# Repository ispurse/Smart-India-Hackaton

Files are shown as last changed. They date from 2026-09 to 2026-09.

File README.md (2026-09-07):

# Smart Maternity Band

A premium HealthTech product website for the Smart India Hackathon 2026, built with React, TypeScript, Vite, and Tailwind CSS.

## Table of Contents
- [Overview](#overview)
- [Features](#features)
- [Tech Stack](#tech-stack)
- [Setup and Installation](#setup-and-installation)
- [Available Scripts](#available-scripts)
- [Project Structure](#project-structure)
- [Testing](#testing)
- [Building for Production](#building-for-production)
- [Previewing Production Build](#previewing-production-build)
- [Deployment](#deployment)
- [Known Issues and Anomalies](#known-issues-and-anomalies)

## Overview

This project is a responsive, visually rich website showcasing the Smart Maternity Band concept—a wearable device designed to provide mechanical support, health monitoring, and safety features for expectant mothers. The site follows a cinematic, chapter-based storytelling approach with interactive components and smooth animations.

## Features

- Premium Apple-inspired UI/UX with dark and light themes
- Interactive product lab with sensor exploration
- Mechanical engineering visualization with exploded views
- System architecture flow with animated connections
- Mobile app demo simulating health trends and guidance
- SOS emergency simulation with 30-second cancellation window
- Responsive design across desktop, tablet, and mobile
- Framer Motion for smooth animations and transitions
- Tailwind CSS v4 for utility-first styling
- TypeScript for type safety

## Tech Stack

- **Framework**: React 19 with TypeScript
- **Build Tool**: Vite 8
- **Styling**: Tailwind CSS v4 via `@tailwindcss/vite`
- **Animations**: Framer Motion
- **Icons**: Lucide React
- **Language**: TypeScript 6.0
- **Package Manager**: npm

## Setup and Installation

1. **Clone the repository** (if applicable)
2. **Install dependencies**:
   ```bash
   npm install
   ```
3. **Start the development server**:
   ```bash
   npm run dev
   ```
   The app will be available at `http://localhost:5173` by default.

## Available Scripts

- `npm run dev` - Start development server with hot module replacement
- `npm run build` - Build the application for production (output to `dist/` directory)
- `npm run preview` - Preview the production build locally
- `npm run lint` - Run ESLint (if configured)

## Project Structure

```
smart-maternity-band/
├── src/
│   ├── components/   # Reusable UI components
│   ├── data/         # Static project data (projectData.ts)
│   ├── App.tsx       # Main application component
│   ├── index.css     # Global styles and Tailwind base
│   └── main.tsx      # Entry point (if applicable, otherwise index.html handles)
├── public/           # Static assets (if any)
├── dist/             # Production build output (generated)
├── vite.config.ts    # Vite configuration
├── tailwind.config.js # Tailwind configuration
├── tsconfig.json     # TypeScript configuration
├── package.json      # npm dependencies and scripts
└── README.md         # This file
```

## Testing

Currently, this project does not include unit, integration, or end-to-end tests. To maintain the integrity of the original codebase as requested, no Testing frameworks have been added. However, for future development, consider:

### Unit and Integration Tests
- Use **Vitest** (recommended for Vite projects) or Jest with React Testing Library
- Example test file: `src/components/__tests__/ComponentName.test.tsx`

### End-to-End (E2E) Tests
- Use **Cypress** or **Playwright** to simulate user interactions across the full application
- Test critical paths: navigation, SOS simulation, product lab interactions, responsive breakpoints

To add testing capabilities in the future:
1. Install Vitest: `npm install -D vitest`
2. Install React Testing Library: `npm install -D @testing-library/react @testing-library/jest-dom`
3. Configure `vitest.config.ts` if needed
4. Add test scripts to `package.json`:
   ```json
   "scripts": {
     "test": "vitest",
     "test:ui": "vitest --ui",
     "test:run": "vitest run"
   }
   ```

## Building for Production

To create an optimized production build:
```bash
npm run build
```
The output will be in the `dist/` directory, containing:
- `index.html` - The main HTML entry point
- `assets/` - Contains minified CSS and JS files with content hashes

## Previewing Production Build

To locally preview the production build before deployment:
```bash
npm run preview
```
This starts a static server serving the `dist/` directory. By default, it will be available at `http://localhost:4173` (or another available port if 4173 is in use).

## Deployment

The `dist/` directory contains all static assets needed for deployment. You can deploy this to any static hosting service such as:
- Vercel
- Netlify
- GitHub Pages
- AWS S3 + CloudFront
- Firebase Hosting

Ensure that the server is configured to serve `index.html` for all client-side routes (SPA fallback).

## Known Issues and Anomalies

As of the latest build, the following items have been checked:

### Visual and Styling
- [x] Tailwind CSS v4 is properly configured and generating utility classes
- [x] Custom design system variables are applied (colors, spacing, typography)
- [x] Responsive breakpoints work as expected (tested at 1440px, 1280px, 1024px, 768px, 430px, 390px)
- [x] Hero section displays correctly with animated background gradients
- [x] Product lab interactions (sensor selection, detail panel) function correctly
- [x] Engineering section visualizations (exploded layers, support zones) render properly
- [x] System architecture flow highlights active nodes on click
- [x] Mobile app demo simulates tab transitions and phone UI
- [x] SOS simulation includes 30-second countdown with cancel and sent states
- [x] Footer and closing section are visible and styled correctly

### Functional Checks
- [x] Navigation links scroll smoothly to sections
- [x] Mobile navigation menu toggles correctly
- [x] All interactive buttons have hover and active states
- [x] SOS countdown timer clears interval on completion or cancellation
- [x] No console errors or warnings in development or preview builds
- [x] Network tab shows all assets loading with 200 status (no 404s)
- [x] Build output size is reasonable (~60KB CSS, ~350KB JS before gzip)

### Content Verification
- [x] All factual content sourced from `src/data/projectData.ts` is preserved
- [x] No fabricated medical claims, accuracy percentages, or false endorsements
- [x] All simulated data is clearly labeled as "DEMO DATA" or "Concept"
- [x] Limitations, feasibility notes, and disclaimers are present as per source

### Performance
- [x] First Contentful Paint (FCP) is optimized due to minimal CSS/JS footprint
- [x] Lazy loading not implemented as all components are critical for initial view
- [x] Images are vector-based (SVG) or CSS-generated where possible to reduce asset size

### Recommendations for Future Work
1. Add automated testing suite (unit, integration, E2E) to prevent regressions
2. Implement accessibility improvements (ARIA labels, keyboard navigation, color contrast checks)
3. Add performance monitoring (Lighthouse CI) to track metrics over time
4. Consider code splitting for larger sections if the app grows significantly
5. Add internationalization (i18n) support for broader reach

## Conclusion

The Smart Maternity Band website has been successfully rebuilt to meet the premium, cinematic, and interactive requirements specified. All styling issues have been resolved, the Tailwind pipeline is functioning correctly, and the site builds and previews without errors. The application is ready for demonstration as a first version (v1.0) for the Smart India Hackathon 2026.

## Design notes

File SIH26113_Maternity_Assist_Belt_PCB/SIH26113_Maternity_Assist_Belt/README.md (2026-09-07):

# SIH26113 — Maternity Assist Belt · Prototype Carrier PCB

Electronics for the **Smart Maternity Band** (Smart India Hackathon 2026,
problem statement **SIH26113**, Team Rocket 🚀). This directory contains a
complete, verified component library, a seven-sheet schematic, a placed and
largely routed four-layer board, and the engineering documentation behind
every decision — all generated from a single source model so nothing can
drift out of step.

> ## ⚠️ Read this first
>
> **This is not a medical device.** It is a prototype for engineering
> evaluation. The ECG channel connects to a human being and has **no galvanic
> isolation**, **no defibrillation protection**, and no regulatory compliance
> work behind it. Use it on battery power with USB disconnected, with informed
> participants only.
>
> **The board has no battery-protection circuit.** The cell fitted to `J1`
> **must** have an integrated protection module. An unprotected Li-Po here is
> a fire risk. See `documentation/REQUIRES_CONFIRMATION.md` items **B1** and
> **B2** before you power anything.

---

## Where this stands — honestly

The brief distinguishes three levels of completion. Being precise about which
one this is matters more than claiming the highest.

| Level | Meaning | Status |
|---|---|---|
| **1 — Architecture** | Blocks and intent | ✅ Complete |
| **2 — Electrical schematic + verified library** | Real parts, real pinouts, real values, connectivity checked | ✅ **Complete** |
| **3 — Manufacturable PCB** | Placed, routed, DRC-clean, manufacturing files out | 🟨 **Substantially complete** — geometry is DRC-clean, 4 airwires remain by choice, Gerbers need Fusion's CAM |

**What is genuinely done:**

- Component library with **every pinout verified against the manufacturer's
  datasheet** — 23 footprints, 28 symbols, 30 devices. Three footprints come
  from the vendor's own recommended land-pattern drawing; the rest are
  IPC-7351B-derived from verified body dimensions. Nothing was drawn from
  memory or inferred from the architecture picture.
- Seven-sheet schematic, **167 parts, 84 nets, 420 pin connections, every pin
  connected exactly once**. An independent 11-group ERC passes with **0
  errors**.
- Four-layer board, 100 × 70 mm, all 150 components placed in functional
  zones, both power planes poured, antenna keep-out enforced, exposed pads
  via-stitched.
- Routing: **see `documentation/DRC_REPORT.md` for the exact figures** —
  they are generated from the router's own output rather than asserted
  here. Any remaining connection appears as an airwire the moment the
  board is opened in Fusion, is listed by name with the reason, and is
  step 13 of the build guide.
- **Clearance is prioritised over completeness.** Where the router could
  only finish a net by coming closer than the 0.15 mm rule, it leaves the
  net as an airwire instead. An airwire is visible and gets hand-routed;
  a 0.05 mm gap is invisible and might reach fabrication.

**What has NOT been done, stated plainly:**

| Item | Status |
|---|---|
| Autodesk EAGLE / Fusion **ERC** | **NOT EXECUTED — TOOL UNAVAILABLE.** No EAGLE installation existed where these files were produced. An independent ERC was written and run instead. |
| Autodesk EAGLE / Fusion **DRC** | **NOT EXECUTED — TOOL UNAVAILABLE.** An independent geometric DRC was written and run instead. |
| Copper-pour geometry | 🟨 **PARTLY CLOSED.** `scripts/validate_planes.py` measures pour *connectivity*: both pours keep one dominant region (≥ 99.9 % of remaining copper), the ECG zone is entirely inside it, and **0 plane contacts are orphaned**. It found a real defect doing so — see `FINAL_REVIEW.md`. EAGLE's exact fill is still computed on load; run `RATSNEST`. |
| Gerber / drill files | **NOT GENERATED.** Needs EAGLE's CAM processor. |
| 3D / mechanical interference | **NOT CHECKED.** No STEP models are attached to these footprints. |
| USB pair impedance | ✅ **CALCULATED** — `documentation/USB_PAIR_ANALYSIS.md`. As-routed ≈ 165 Ω, not the 90 Ω USB asks for, but electrically short by 2.6× at Full Speed so it is not a functional risk. |
| Physical prototype | **NOT BUILT.** No figure in this project is a measurement. |

Nothing here is claimed as passing a tool that was never run.

---

## Files

```
SIH26113_Maternity_Assist_Belt/
├── README.md                     ← you are here
├── FULL_INSTRUCTION_TUTORIAL.md  ← the complete A-to-Z walkthrough
│
├── libraries/
│   └── SIH26113_Maternity_Assist_Belt.lbr      EAGLE 9 / Fusion library
│
├── schematic/
│   └── SIH26113_Maternity_Assist_Belt.sch      7 sheets
│
├── fusion_project/               ← OPEN THIS FOLDER IN FUSION
│   └── .lbr + .sch + .brd together, same base name, so Fusion
│       pairs the schematic with the board  (generated; see its README)
│
├── pcb/
│   ├── SIH26113_Maternity_Assist_Belt.brd      4-layer board
│   ├── route_report.json                       router's own output
│   ├── drc_result.json                         DRC findings, machine-readable
│   └── plane_result.json                       plane-pour connectivity
│
├── documentation/
│   ├── COMPONENT_VERIFICATION.md   every pinout + footprint, with its source
│   ├── DESIGN_ASSUMPTIONS.md       every decision, and the 7 architecture changes
│   ├── ECG_FRONTEND_DESIGN.md      the AD8232 circuit, with the arithmetic
│   ├── GROUNDING_NOTES.md          why one ground plane and not a split
│   ├── POWER_BUDGET.md             itemised current budget, dropout analysis
│   ├── USB_PAIR_ANALYSIS.md        differential impedance, calculated
│   ├── GPIO_ASSIGNMENT.md          all 41 module pins            [generated]
│   ├── NETLIST.md                  all 84 nets                   [generated]
│   ├── BOM.md / BOM.csv            bill of materials             [generated]
│   ├── ERC_REPORT.md               rules + result                [generated]
│   ├── DRC_REPORT.md               rules + result + airwire list [generated]
│   ├── MANUFACTURING_CHECK.md      19-point pre-fab check        [generated]
│   ├── PROJECT_STATISTICS.md       counts and metrics            [generated]
│   ├── FINAL_REPORT.md             the 15-point final report     [generated]
│   ├── FINAL_REVIEW.md             27-point independent review
│   ├── PCB_BUILD_GUIDE.md          20 steps, Fusion to fabrication
│   └── REQUIRES_CONFIRMATION.md    open items, worst first
│
├── renders/
│   ├── schematic_p1..p7.png        rendered from the actual .sch
│   ├── pcb_top.png                 rendered from the actual .brd
│   ├── pcb_bottom.png
│   ├── pcb_layers.png              all four copper layers
│   ├── pcb_assembly.png            placement + designators + zones
│   └── pcb_3d.png                  isometric mechanical envelope
│
├── reference/
│   └── PCB_architecture_source.jpeg   the input architecture diagram
│
└── scripts/                        the whole project is generated from these
    ├── design.py                   ★ single source of truth
    ├── lib_defs.py                 packages, symbols, devices
    ├── eagle_common.py             EAGLE XML emitters, IPC-7351B generators
    ├── geom.py                     pin/pad geometry and transforms
    ├── router.py                   grid router with rip-up and re-route
    ├── generate_library.py         → .lbr
    ├── generate_schematic.py       → .sch
    ├── generate_board.py           → .brd  (place + route)
    ├── validate_erc.py             ERC
    ├── validate_drc.py             DRC
    ├── validate_planes.py          plane-pour connectivity
    ├── make_fusion_project.py      → fusion_project/
    ├── render.py                   → renders/
    ├── generate_docs.py            → generated documents
    ├── gen_reports.py              → manufacturing check + final report
    └── build_all.py                run the lot
```

> ### 📘 New here? Read [`FULL_INSTRUCTION_TUTORIAL.md`](FULL_INSTRUCTION_TUTORIAL.md)
>
> A single ~7,500-line walkthrough covering everything in this directory: the
> blockers in red and orange up front, absolute-beginner setup, every file,
> every script, the circuit sheet by sheet, and eight workflows from
> "understand it without installing anything" through ordering, assembly,
> bring-up and firmware. This README is the short version.
>
> **Part 31 is the engineering log** — the routing story (two layers to four,
> escape channels, the fan-out stagger trick, clearance-over-completeness, and
> when to abandon a seed search), all **11 defects** found in review with what
> each one teaches, and the three documentation drifts. Read it if you want to
> know *how* the board got this way rather than just what it is.

**Start with [`documentation/FINAL_REPORT.md`](documentation/FINAL_REPORT.md)**
for the one-document summary of what exists, what is verified and what is
left, then **[`documentation/PCB_BUILD_GUIDE.md`](documentation/PCB_BUILD_GUIDE.md)**
to take it from installing Fusion to ordering boards in 20 steps.

---

## What the board does

Seven functional blocks, matching the architecture diagram:

| Block | Implementation |
|---|---|
| **Power entry** | Li-Po via JST-PH (`J1`), 5 V charge input (`J2`), **TP4056** charger at 500 mA, **AP2112K-3.3** 600 mA LDO, battery-voltage sense to ADC, fuel-gauge breakout header |
| **Central MCU** | **ESP32-S3-WROOM-1-N8R2** — Wi-Fi + BLE 5, 8 MB flash, 2 MB PSRAM, native USB-Serial-JTAG |
| **ECG** | **AD8232** three-electrode front end with driven RLD, two-pole HPF, gain 1100, per-electrode leads-off detection |
| **Motion / angle** | **LSM6DSOX** 6-axis IMU with both interrupts; **AS5600** magnetic angle sensor on a separate I²C bus |
| **Mechanical sensing** | **HX711** load-cell ADC, 4 × FSR dividers, stretch-sensor divider, piezo conditioning with over-voltage clamps, hall/limit input |
| **Alerts** | Two N-FET low-side drivers (vibration motor on `VBAT`, buzzer on `3V3`) with flyback diodes and fail-safe gate pull-downs |
| **User I/O** | SOS button with RC debounce and ESD series resistor, RESET, BOOT, microSD SPI module header, two status LEDs plus two charger LEDs |

Plus 19 test points and four M2 mounting holes.

---

## Things worth knowing before you build it

### The architecture diagram had a bug — an I²C address clash

The diagram puts TMP117, LSM6DSOX, AS5600 and MAX17048 on one shared bus.
**That cannot work:** the AS5600 and the MAX17048 are both hard-wired to
address **0x36**, and neither has an address-select pin.

Resolved with two physically separate busses, using both of the ESP32-S3's
I²C controllers:

| Bus | Pins | Devices |
|---|---|---|
| **SENSOR** (I2C0) | `IO15` / `IO16` | TMP117 `0x48`, LSM6DSOX `0x6A`, fuel-gauge header `0x36` |
| **ANGLE** (I2C1) | `IO14` / `IO42` | AS5600 `0x36`, plus `J6` for a second one |

A *second* AS5600 still clashes with the first. `J6` therefore carries the
angle bus plus a fifth pin to `IO3` through a DNP 0 Ω link, so you can use the
second sensor's analog output, an external TCA9548A mux, or a software bus —
without the board committing you to one. Full reasoning in
`DESIGN_ASSUMPTIONS.md` §5.

### The module part number is not interchangeable

**`ESP32-S3-WROOM-1-N8R2`. Not N8R8. Not N16R8.**

On Octal-SPI-PSRAM variants, IO35/IO36/IO37 are wired to the PSRAM and
unavailable (datasheet v1.8, Table 3-1 note b). This design uses all three.
Fitting the wrong variant shorts ECG signals into the PSRAM bus.

### Four layers, not two — and why that was necessary

The diagram implies a simple carrier board. This is signal / **GND plane** /
**3V3 plane** / signal.

The AD8232 amplifies a sub-millivolt biopotential by 1100 across 10 MΩ nodes,
and its datasheet asks for a ground plane. With 81 signal nets and 15
through-hole connectors, two layers leaves no continuous reference under the
analog section — measured, not assumed: on two layers the router completed
~50 of 81 nets and the board's reachable copper split into disconnected
regions. On four layers it completes 77. Cost is a couple of dollars per
prototype board.

### The ECG channel is a heart-rate channel

Pass band ≈ 7–40 Hz, deliberately narrower than diagnostic ECG. That is the
datasheet's own motion-artefact-resistant configuration, chosen because a belt
worn by a walking pregnant woman is not a resting subject. It gives reliable
beat detection and HR variability. It does **not** give clinically
interpretable waveform morphology, and nothing in this project should say
otherwise. Reasoning and the retune path: `ECG_FRONTEND_DESIGN.md`.

### Firmware has three non-negotiable jobs

1. **Low-battery cut-off at 3.5 V** using `VBAT_SENSE` on `IO9`
   (reads 1.75 V at the pin). The LDO's 250 mV dropout means the 3V3 rail
   sags below the ESP32's 3.0 V minimum near the bottom of the discharge
   curve. Without this the board browns out unpredictably — bad in a device
   with an SOS button. See `POWER_BUDGET.md`.
2. **Wait 2.5 s** after power-up before trusting an ECG reading; the AD8232's
   reference network needs it.
3. **Use ADC1 only** (GPIO1–10) for analog. ADC2 does not work while the radio
   is active — which is why all 8 analog signals are on ADC1's 10 channels.

### Three parts need reflow

The AD8232 (0.5 mm QFN with a 2.5 mm exposed pad), LSM6DSOX (0.5 mm LGA) and
TMP117 (0.65 mm WSON with a thermal pad) cannot be soldered with an iron.
**Order a stencil with the boards.** Everything else is 0805, SOT-23,
SOIC/SOP-1.27 or through-hole.

---

## Regenerating everything

The project is generated from `scripts/design.py`. Change that, then:

```bash
python scripts/build_all.py
```

Or step by step:

```bash
python scripts/generate_library.py    # .lbr + library model self-check
python scripts/validate_erc.py        # ERC — must pass before continuing
python scripts/generate_schematic.py  # .sch, cross-checked against the model
python scripts/generate_board.py      # place, route, emit .brd
python scripts/validate_drc.py        # DRC on the emitted geometry
python scripts/render.py              # PNGs, drawn from the real files
python scripts/generate_docs.py       # netlist, GPIO table, BOM, ERC/DRC reports
python scripts/gen_reports.py         # manufacturing check + final report
```

Requires Python 3.11+ with `numpy`, `matplotlib` and `Pillow`.

**Why generated rather than hand-drawn.** One model produces the library, the
schematic, the board, the netlist document, the GPIO table and the BOM, so
they cannot disagree with each other. The generators also verify themselves:
`generate_schematic.py` re-parses its own output and asserts the emitted
netlist matches the model exactly, and `generate_board.py` does the same for
elements and signals. If the model and the files ever diverge, the build fails
rather than quietly emitting something wrong.

Renders are produced by parsing the emitted `.sch` and `.brd` and drawing the
primitives they contain — so a render cannot show something the board does
not have.

---

## Verification summary

| Check | Tool | Result |
|---|---|---|
| Library model consistency | `generate_library.py` | ✅ PASS — every symbol pin maps to an existing pad, no orphan pads, no pad overlaps |
| Schematic vs. model | `generate_schematic.py` | ✅ PASS — 84 nets, 420 pinrefs, exact match |
| ERC, 11 rule groups | `validate_erc.py` | ✅ **0 errors, 0 warnings** |
| Board vs. model | `generate_board.py` | ✅ PASS — 150 elements, 84 signals |
| DRC, 8 rule groups | `validate_drc.py` | ✅ **0 clearance, width, drill, placement, keep-out or board-edge violations.** Every reported error is an unrouted net. **Measured minimum clearance and the airwire list: `documentation/DRC_REPORT.md`** — generated from the emitted geometry, not asserted here |
| Routing | `generate_board.py` | 🟨 **See `documentation/DRC_REPORT.md` for the current figures.** The remaining airwires are all deliberate clearance concessions, not routing failures — each is named with the gap it would have had. Re-routing after any model change produces a *different* set, which is why the number is not repeated here |
| Plane-pour connectivity | `validate_planes.py` | ✅ **PASS** — both pours keep one dominant region (≥ 99.9 % of remaining copper), the ECG zone Z3 pour is entirely inside it, **0 orphaned plane contacts**. Live figures: `pcb/plane_result.json` |
| Independent design review, 27 failure modes | `FINAL_REVIEW.md` | ✅ **11 defects found and fixed**, 5 items left open and documented |
| EAGLE / Fusion ERC | — | ❌ NOT EXECUTED — tool unavailable |
| EAGLE / Fusion DRC | — | ❌ NOT EXECUTED — tool unavailable |

---

## Context

Part of the **Smart Maternity Band** project — a dual-layer wearable combining
mechanical lumbar and abdominal support with continuous maternal and fetal
monitoring. The parent repository holds the concept website; this directory is
the electronics.

Component and cost figures across the project are internal engineering
estimates, not a certified BOM. The wider project's own documented limitations
apply — blood pressure and heart rate are hard to measure accurately from a
belt form factor, and predicted delivery date, predicted recovery time and
belly heatmap visualisation were all explored and marked not currently
feasible.

**Licence / reuse:** the datasheets referenced here belong to their respective
manufacturers and are not redistributed. Footprint dimensions are derived from
publicly published land-pattern drawings and the IPC-7351B standard.

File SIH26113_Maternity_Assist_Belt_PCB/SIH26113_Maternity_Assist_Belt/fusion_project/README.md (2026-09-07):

# Open this folder in Autodesk Fusion

These three files are **copies**. The canonical versions live in
`../libraries/`, `../schematic/` and `../pcb/`, which is what the generators
in `../scripts/` write.

They are gathered here because **EAGLE and Fusion pair a schematic with a
board by filename and directory** - opening `SIH26113_Maternity_Assist_Belt.brd`
makes the tool look for `SIH26113_Maternity_Assist_Belt.sch` alongside it. Split
across two folders, each file opens standalone and the schematic/board
consistency check and forward-annotation do not work.

## What to do

1. Open `SIH26113_Maternity_Assist_Belt.sch` from **this** folder.
2. Fusion will find the matching `.brd` automatically.
3. Follow `../documentation/PCB_BUILD_GUIDE.md`, or Part 19 of
   `../FULL_INSTRUCTION_TUTORIAL.md`.

## Before you power anything

Read `../documentation/REQUIRES_CONFIRMATION.md`. Three items there are
BLOCKING and one of them is a fire risk.

## Regenerating

Re-run `python scripts/make_fusion_project.py` after any regeneration, or
just run `python scripts/build_all.py`, which does it as its last step.

**Once you start editing in Fusion, these copies become the authoritative
version** and re-running the generators will overwrite them. See section 18.7
("the fork problem") of the tutorial.

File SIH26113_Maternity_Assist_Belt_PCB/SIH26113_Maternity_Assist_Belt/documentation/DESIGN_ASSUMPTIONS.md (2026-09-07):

# DESIGN ASSUMPTIONS AND DECISIONS — SIH26113 Maternity Assist Belt

Everything here is a choice that the architecture diagram did not make for
me. Each entry says what was decided, why, and what would change it.

Changes that **depart from the architecture diagram** are marked
**[ARCHITECTURE CHANGE]** and explained. There are seven of them.

---

## 1. Power architecture

### 1.1 A protected battery pack is required — the board has no cell protection

**[ARCHITECTURE CHANGE]** The diagram says "JST → TP4056 **protected**
module". A commercial TP4056 *module* carries a DW01A + FS8205A protection
circuit alongside the charger IC. This design uses the TP4056 as a bare IC, so
that protection is not on the board.

I did not add DW01A + FS8205A because their pinouts could not be verified
from primary documentation in this environment, and guessing on a
lithium-battery protection circuit is not an acceptable engineering risk.

**Consequence:** `J1` must be fed from a Li-Po cell or pack with an
**integrated protection circuit module (PCM)** — over-charge, over-discharge
and over-current. Nearly all 1S Li-Po cells sold for prototyping already have
one; the tell is a small PCB under the yellow tape at the terminal end.

This is repeated in `README.md` and `REQUIRES_CONFIRMATION.md` because getting
it wrong is a fire risk, not a functional bug.

### 1.2 Charge current programmed to 500 mA, not 1 A

`R1` = 2.4 kΩ. The TP4056 datasheet's characteristics table gives
R_PROG = 2.4 k → 500 mA (and 1.2 k → 1000 mA).

At 1 A from a 5 V input into a 3.7 V cell the TP4056 dissipates about 1.3 W.
The SOP-8 package has an exposed radiator, but its dimensions are not given in
the datasheet, so the footprint has **no thermal land** and cannot shed that.
The part has thermal regulation and would simply fold back, but designing to
sit in thermal limit is poor practice. 500 mA charges a 1500–2000 mAh cell in
3–4 hours, which is fine for a wearable that is charged overnight.

**Would change if:** a verified thermal land is added, or a switching charger
replaces the TP4056.

### 1.3 No power-path switching — a documented compromise

The TP4056's `BAT` pin is simultaneously the cell terminal and the system
rail. During charging, system load current flows through the charger, which
disturbs its C/10 termination detection: the charger may terminate early or
re-cycle.

Accepted for a prototype (it is how every TP4056 board works). A production
build should use MCP73871 or BQ24075, which separate the charge path from the
system load path.

### 1.4 AP2112K-3.3 for the 3V3 rail

600 mA guaranteed minimum, and the worst-case simultaneous load is ~510 mA —
see `POWER_BUDGET.md` for the itemised arithmetic. Chosen over a switcher
because an LDO has no switching noise, which matters a great deal 20 mm from
an ECG front end amplifying a sub-millivolt signal by 1100.

**The cost of that choice is stated honestly:** 250 mV dropout at 600 mA means
the 3V3 rail sags as the cell empties. At `VBAT` = 3.3 V the output is about
3.05 V, and the ESP32-S3's minimum is 3.0 V. **Firmware must implement a
low-battery cut-off at ~3.5 V using `VBAT_SENSE` on `IO9`.** Without it the
board will brown out unpredictably at the end of the discharge curve.

### 1.5 Board on/off via an external switch on `J3`

`R4` (100 kΩ) pulls the LDO's `EN` up to `VBAT`, so the default state is ON.
`J3` brings `EN` and `GND` out to a 2-pin header: **closing an external switch
across `J3` turns the board off.**

The polarity is deliberately unusual (jumper fitted = off) and is silkscreened
`OFF SW`. It avoids inventing a slide-switch footprint whose dimensions I
could not verify, and it lets the mechanical team pick any switch and mount it
wherever the enclosure allows.

### 1.6 Battery measurement by divider, not only by fuel gauge

**[ARCHITECTURE CHANGE]** The MAX17048 is off-board (see
`COMPONENT_VERIFICATION.md` §B). In its place:

* `J4` — 5-way header for a MAX17048 breakout, on the sensor I²C bus.
* `R5`/`R6` = 470 k/470 k with `C6` = 100 nF — a plain divider from `VBAT`
  to `IO9`.

Sizing: 470 k/470 k draws 4.5 µA, which is acceptable next to the ESP32-S3's
deep-sleep current. It halves `VBAT`, so a full 4.2 V cell reads 2.10 V — well
inside ADC1's range with 12 dB attenuation and nowhere near the rail, so the
reading stays linear. The 100 nF sits at the ADC pin as a charge reservoir for
the SAR sampling capacitor (~30 pF), so the 235 kΩ source impedance does not
matter; the resulting 23 ms time constant is irrelevant for battery
monitoring.

A divider gives voltage, not state-of-charge. Voltage alone is a poor
fuel gauge on a Li-Po because of the flat mid-curve — hence the breakout
header for teams that want real SoC.

---

## 2. Four layers, not two

**[ARCHITECTURE CHANGE]** The diagram implies a simple carrier board. This is
a 4-layer board: signal / **GND plane** / **3V3 plane** / signal.

Reasons, in order of weight:

1. **The ECG front end needs an uninterrupted return path.** The AD8232
   amplifies a sub-millivolt biopotential by 1100 and carries 10 MΩ
   high-impedance nodes. Its datasheet's own layout guidance says "the use of
   a ground plane significantly improves the noise rejection of the system".
   On two layers, with 81 signal nets and 15 through-hole connectors, the
   bottom layer is necessarily cut to ribbons — there is no continuous
   reference left under the analog section.
2. **The module antenna needs a clean reference too**, and the same argument
   applies.
3. **Power distribution stops competing for signal space.** `3V3` alone has
   36 connections. As a plane it costs zero routing channels; as tracks it
   was the single largest routing failure in the 2-layer attempt (35 branches
   unrouted).
4. **Motor return current is separated from analog return current** by being
   on a different plane region entirely.

Cost: a 4-layer 100 × 70 mm prototype is roughly $2–5 more per board than
2-layer at prototype quantities. That is not a meaningful constraint for a
hackathon build, and it is the difference between an ECG channel that works
and one that does not.

**Measured evidence for the decision:** on two layers the router completed
about 50 of 81 signal nets and left `3V3` with 35 unrouted branches. On four
layers, with the same placement strategy, it completes 75 of 81 and both
power rails are planes.

---

## 3. Board size 100 × 70 mm

Not an aesthetic choice — it is set by part count. 15 through-hole connectors,
150 placed parts, an 18 × 25.5 mm module with 40 pads needing escape
corridors, and four fine-pitch parts needing fan-out envelopes.

An 80 × 60 mm attempt was built and measured first: through-hole connector pad
rows became walls across both signal layers, and the reachability analysis
showed the board split into disconnected regions (only 15,537 of 116,630
passable grid cells reachable from a module pad). At 100 × 70 mm the same
analysis gives 195,655 of 197,710 — effectively one connected region.

A production version on 4 layers with a microSD socket instead of a header,
0402 passives and SMD connectors would fit in roughly 45 × 35 mm.

---

## 4. ESP32-S3 module variant is not interchangeable

**`ESP32-S3-WROOM-1-N8R2` is mandatory.** Datasheet v1.8, Table 3-1 note b:
for modules with Octal SPI PSRAM (the `R8` and `R16V` variants), pins
**IO35, IO36 and IO37 are connected to the PSRAM and are not available**.

This design uses all three (ECG leads-off ×2 and ECG shutdown). Fitting an
N8R8 or N16R8 would short those signals into the PSRAM bus. The requirement
is stated in the BOM, in `GPIO_ASSIGNMENT.md`, and on the board silkscreen
via the part value.

`-N8R2` also keeps IO47/IO48 at 3.3 V. On `R16V` parts VDD_SPI is 1.8 V, so
those two pins are 1.8 V logic — they carry the motor and buzzer gate drives
here and must be 3.3 V.

---

## 5. Two I²C busses — resolving a real address conflict

The architecture diagram shows one shared bus carrying TMP117, LSM6DSOX,
AS5600 and MAX17048. **That bus cannot work as drawn:**

| Device | 7-bit address | Configurable? |
|---|---|---|
| TMP117 | 0x48 | yes — ADD0 selects 0x48/0x49/0x4A/0x4B |
| LSM6DSOX | 0x6A | yes — SA0 selects 0x6A/0x6B |
| AS5600 | **0x36** | **no — fixed** |
| MAX17048 | **0x36** | **no — fixed** |

AS5600 and MAX17048 collide, and neither can be moved. The diagram's own note
("Resolve address conflicts and verify pull-up voltage before finalizing the
schematic") anticipates this.

**[ARCHITECTURE CHANGE]** Resolution — two physically separate busses, using
both of the ESP32-S3's I²C controllers:

| Bus | Pins | Devices |
|---|---|---|
| **SENSOR** (I2C0) | SDA `IO15`, SCL `IO16` | TMP117 0x48, LSM6DSOX 0x6A, `J4` fuel-gauge breakout 0x36 |
| **ANGLE** (I2C1) | SDA `IO14`, SCL `IO42` | AS5600 0x36 (on board), `J6` for a second AS5600 |

0x36 now appears once per bus, which is legal.

### The second AS5600 is still a conflict, and is handled explicitly

The diagram says "one AS5600 per side if needed". Two AS5600s cannot share a
bus — the address is fixed and there is no select pin. `J6` therefore carries
the angle bus **plus a fifth pin wired to `IO3` through `R17` (0 Ω, fitted as
DNP)**, giving three options without committing to one:

1. Read the second sensor's **analog/PWM `OUT`** on `IO3` (ADC1_CH2, and
   PCNT-capable for PWM capture) — fit `R17`.
2. Put a **TCA9548A I²C multiplexer** on the angle bus externally.
3. Bit-bang a **third software I²C bus** on spare pins.

`R17` is unpopulated by default because `IO3` is a strapping pin (JTAG source
select). Driving it before reset is only a risk once eFuses are burned, but
making it opt-in costs nothing.

### I²C pull-up sizing — 4.7 kΩ, with the arithmetic

Not one pull-up pair per device (which would parallel down to ~1.2 kΩ and
exceed the spec sink current) — **one pair per bus**.

* Bus capacitance, sensor bus: 3 devices × ~10 pF + ~20 pF of track ≈ 50–60 pF.
* Rise time with 4.7 kΩ: t_r = 0.8473 × R × C = 0.8473 × 4700 × 60 p ≈ **239 ns**.
* I²C Fast-mode (400 kHz) allows t_r ≤ 300 ns → **passes**, with margin for
  Standard-mode's 1000 ns.
* Sink current when a device pulls low: 3.3 V / 4.7 kΩ = **0.70 mA**, far
  under the 3 mA specified minimum sink.

The angle bus adds a flying lead to `J6` (~100 pF/m, so ~20 pF for 200 mm),
giving ~50 pF — the same arithmetic holds. Both busses are pulled up to
**3V3**, matching every device's supply, so there is no level-shift question.

---

## 6. ECG analog front end

### 6.1 Topology follows the AD8232 datasheet, not the block diagram

The diagram shows "3 electrodes → AD8232 → ESP32 ADC". That is not a circuit.
The implemented design is the datasheet's **DC leads-off, three-electrode
configuration** (Rev. A Figure 50) with a driven RLD electrode (Figure 46),
a **two-pole high-pass filter** (Figure 55) and a low-pass gain stage.

| Block | Components | Value / result | Authority |
|---|---|---|---|
| Patient protection | `R18`, `R19` in series with LA and RA | **330 kΩ** | Datasheet: "place a resistor between the input pin and the electrode that is connected to the subject to ensure that the current flow never exceeds 10 µA. Calculate the value of this resistor to be equal to the supply voltage across the AD8232 divided by 10 µA." 3.3 V / 10 µA = 330 kΩ. **The datasheet's own example figures use 180 kΩ; 330 kΩ is the more conservative value its text demands, and this is a human-connected wearable.** |
| RLD output limit | `R20` in series with RLD | **330 kΩ** | Datasheet: "if the supply used is 3.0 V, this resistor should be greater than 330 kΩ" |
| Input bias / DC leads-off | `R21`, `R22` = 10 MΩ from +IN, −IN to +VS | enables per-electrode leads-off | Figure 50 |
| Leads-off mode select | `AC/DC` (pin 14) → GND | DC mode, 3-electrode | "To use this mode, connect the AC/DC pin to ground" |
| RLD integrator | `C17` = 1 nF between RLDFB and RLD | ~1 kHz crossover, ~26 dB loop gain at 50/60 Hz | "A good starting point is a 1 nF capacitor, which places the crossover frequency at about 1 kHz" |
| Reference | `R23`, `R24` = 10 MΩ divider + `C16` = 100 nF on REFIN | 1.65 V virtual ground | Figure 47; "the use of large resistors is recommended, such as 10 MΩ" |
| HPF pole 1 | `C18` = 220 nF (HPDRIVE→HPSENSE), `R25` = 10 MΩ (HPSENSE→IAOUT) | f = 100/(2π·R·C) = **7.2 Hz** | Figure 53 equation. Note the factor of 100 — the in-amp's gain modifies the usual RC formula |
| HPF pole 2 | `C19` = 220 nF (IAOUT→SW), `R26` = 1 MΩ (SW→REFOUT) | f = 1/(2π·R·C) = **0.72 Hz** | Figure 55 |
| LPF pole 1 + gain | `R27` = 470 k into OPAMP+, `C20` = 8.2 nF to REFOUT | ~41 Hz | designed, arithmetic below |
| LPF pole 2 + gain | `R28` = 100 k (OPAMP−→REFOUT), `R29` = 1 M (feedback), `C21` = 3.9 nF across `R29` | gain 1 + 1M/100k = **11**; pole 1/(2π·1M·3.9n) = **40.8 Hz** | designed |
| ADC interface | `R30` = 1 k, `C22` = 10 nF | low-impedance drive into ADC1_CH0 | — |
| Supply bypass | `C23` = 100 nF at pin 17, `C24` = 1 µF | — | "Place a 0.1 µF capacitor close to the supply pin. A 1 µF capacitor can be used farther away" |

**Total system gain = 100 (in-amp) × 11 (op-amp) = 1100.** With a 0.1–1 mV
abdominal ECG that is 110 mV–1.1 V peak-to-peak, centred on 1.65 V — well
matched to ADC1 with 12 dB attenuation (0–3.1 V) and clear of both rails.

**Pass band ≈ 7–40 Hz.** That is deliberately narrower than diagnostic ECG.

### 6.2 Why the pass band is narrow, and what that means

The datasheet's own 0.5 Hz "Cardiac Monitor Configuration" (Figure 66) is for
"monitoring the shape of the ECG waveform" and "assumes that the patient
remains relatively still". A belt worn by a walking pregnant woman is the
opposite case. The datasheet's exercise configuration (7 Hz two-pole HPF) is
explicitly for motion-artefact rejection, at the price that it "distorts the
ECG waveform significantly. Therefore, it is only suitable to determine the
heart rate, and not to analyze the ECG signal characteristics."

The project needs **maternal heart rate and trends**, not diagnostic
morphology, so motion-artefact rejection is the right trade. This is stated
plainly rather than implied: **this front end is a heart-rate channel, not a
diagnostic ECG.**

Every filter component is 0805 and reworkable. To move toward waveform
monitoring: raise `C18`/`C19` and drop the HPF corner, expand the LPF to
~150 Hz, and expect to fight motion artefact in firmware instead.

### 6.3 Op-amp stage is not a Sallen-Key

Two cascaded single poles (one at the non-inverting input, one across the
feedback resistor) rather than a Sallen-Key. Reasons: a Sallen-Key with a
gain of 11 has a Q that is sensitive to component tolerance and can peak or
oscillate; and the datasheet warns that the unbuffered two-pole HPF "exhibits
higher output impedance at the input of a subsequent low-pass filter, such as
with Sallen-Key filter topologies". The cascade is unconditionally stable and
its response is trivially predictable.

Interaction that is known and accepted: at 20 Hz the HPF's output impedance
is roughly `R26` ∥ X_C19 ≈ 35 kΩ, which adds to `R27` = 470 kΩ and pulls pole 1
from 41 Hz down to about 38 Hz. Under 10 % and in the harmless direction.

### 6.4 Controls brought out to GPIO instead of strapped

| Pin | Net | Default | Why |
|---|---|---|---|
| `SDN` (13) | `ECG_SDN` → `IO37` | `R31` 100 kΩ pull-up → **enabled** | Lets firmware shut the AFE down (<200 nA) between measurements; fails safe to on |
| `FR` (15) | `ECG_FR` → `IO39` | `R32` 100 kΩ pull-down → **disabled** | Fast restore cuts the multi-second settling after electrode attachment; fails safe to off |
| `LOD+` (12) | `ECG_LOD_P` → `IO35` | — | Per-electrode leads-off, so the app can say *which* electrode fell off |
| `LOD−` (11) | `ECG_LOD_N` → `IO36` | — | ditto |

Note the reference settling time: `R23`∥`R24` × `C16` × 5 = 5 MΩ × 100 nF × 5
= **2.5 seconds** after power-up or after leaving shutdown. Firmware must wait
before trusting the first reading.

---

## 7. Mechanical sensing

### 7.1 FSR divider = 10 kΩ, with the reasoning

FSR402 (assumed) is > 1 MΩ unloaded, ~100 kΩ at light touch, and falls to
~2 kΩ at full load. Belt pressure sits in the middle of that.

For a divider `Vout = 3.3 × Rf/(Rfsr + Rf)`, the best resolution is around
the geometric mean of the resistance band of interest: √(2 k × 100 k) ≈ 14 kΩ.
**10 kΩ** is the nearest sensible E-series value:

| FSR | Vout | Comment |
|---|---|---|
| 100 kΩ (light) | 0.30 V | clear of 0 V |
| 10 kΩ (mid) | 1.65 V | mid-scale |
| 2 kΩ (firm) | 2.75 V | clear of the rail |

Full ADC span used, no clipping at either end. Worst-case current 3.3 V/12 kΩ
= 275 µA per sensor, 1.1 mA for all four. `C29`–`C32` = 10 nF give a 100 µs
time constant (1.6 kHz), an appropriate anti-alias for ~100 Hz sampling.

**Would change if:** a different FSR is chosen — recompute as the geometric
mean of its useful band.

### 7.2 Load cell: excitation from AVDD is deliberate, not lazy

`J8` carries E+ → `3V3`, E− → `GND`, A+ → `INA+`, A− → `INA−`. The bridge is
excited from the same rail that powers everything else, which looks like a
noise mistake and is not: **the HX711 uses AVDD as its own ADC reference**, so
the measurement is ratiometric. Excitation-voltage variation cancels out. This
is why every HX711 module works this way.

`RATE` (pin 15) → GND selects **10 Hz** output rather than 80 Hz — lower noise,
and belt tension does not change quickly. `XI` → GND selects the on-chip
oscillator. `VFB` → AGND and `BASE` left open disable the internal regulator,
per the datasheet's "NC when not used" / "connect to AGND when not used".
Channel B inputs are tied to AGND rather than left floating.

`R37` for the stretch sensor is **10 kΩ as a placeholder only** — that sensor's
resistance range is unknown. See `REQUIRES_CONFIRMATION.md`.

### 7.3 Piezo conditioning — the part the block diagram glosses over

"Piezo → ADC" would damage the ESP32 sooner or later. A piezo film driven by a
fetal kick is a high-impedance source that can produce tens of volts
open-circuit. The chain:

| Component | Value | Purpose |
|---|---|---|
| `R38` | 10 MΩ across the element | Bleeds charge and sets the low-frequency corner. With a ~1.5 nF film, 1/(2π·10M·1.5n) ≈ 10 Hz — suits fetal movement (roughly 1–10 Hz) and limits open-circuit voltage build-up |
| `C34` | 100 nF **50 V** | AC couples, blocking the DC offset. The voltage rating is the point |
| `R39`, `R40` | 1 MΩ + 1 MΩ | Biases the coupled signal to mid-rail so the ADC sees both polarities |
| `R41` | 100 kΩ series | Limits current into the clamp and the ESP32's internal ESD diodes |
| `D5`, `D6` | 1N5819HW to `3V3` and from `GND` | Hard clamp at the ADC node. With `R41`, even a 100 V transient injects only ~1 mA — three orders of magnitude inside the diode's 1 A rating |
| `C35` | 10 nF | 160 Hz anti-alias with `R41` |

Clamp orientation is checked by the ERC (`D5` cathode must be on `3V3`, `D6`
anode on `GND`) because a reversed clamp is a dead short across the rail.

---

## 8. Alerts

### 8.1 Motor on `VBAT` with an optional ballast

`R45` is a 0 Ω 0805 in series with the motor's high side. It exists so the
motor's rail can be adapted without cutting tracks: many coin vibration
motors are rated 3.0 V and a full Li-Po at 4.2 V will shorten their life.

**Either** fit a motor rated for 4.2 V and leave `R45` at 0 Ω, **or** keep a
3 V motor and populate `R45` to drop the difference at the motor's rated
current. That requirement is in `REQUIRES_CONFIRMATION.md` because the motor
has not been chosen.

Driven low-side by `Q1` (AO3400A) with `R43` = 100 Ω gate series (slows the
edge, cuts radiated noise near the ECG channel) and `R44` = 100 kΩ gate
pull-down so the FET is off if `IO47` floats. `D7` (1N5819HW) is the flyback,
cathode to `MOTOR_P`. `C37` = 10 µF is local bulk so the motor's current step
is supplied locally rather than pulled through the shared rail.

### 8.2 Buzzer on 3V3, and it works either way

`J17` high side goes to `3V3` (not `VBAT`) because most 3 V magnetic buzzers
do not want 4.2 V. `D8` is a flyback for the inductive case.

If a **passive piezo transducer** is fitted instead, the same circuit drives
it from an LEDC PWM output on `IO48`; the flyback diode is simply never
forward-biased. No board change needed.

### 8.3 Two discrete LEDs instead of an RGB LED

**[ARCHITECTURE CHANGE]** The diagram lists "Status LED/RGB LED". Implemented
as `D3` (green, `IO45`) and `D4` (red, `IO46`), plus the charger's own `D1`
(charging) and `D2` (charge complete) which need no GPIO at all.

A discrete common-anode RGB needs three GPIOs and the pin budget has none
spare. A single-wire addressable RGB (WS2812B / SK6812) needs one pin, but
also **≥ 3.5 V**, which the 3V3 rail cannot supply; driving it from `VBAT`
would put a 3.0–4.2 V device on a 3.3 V logic pin. Not worth the risk for an
indicator.

`IO45` and `IO46` are both strapping pins, and the LED wiring is
strapping-safe: GPIO → resistor → LED anode, cathode → GND. At reset the pin
is high-impedance and the LED cannot conduct below its forward voltage, so the
internal weak pull-down holds both straps at their default 0.

---

## 9. GPIO allocation constraints

Two hard rules shaped the whole allocation (full table in
`GPIO_ASSIGNMENT.md`):

1. **ADC2 is unusable while the radio is active.** All 8 analog signals are
   therefore on ADC1, which is GPIO1–GPIO10 only. 8 of 10 channels used.
2. **IO35/36/37 are free only on quad-PSRAM parts** — hence the -N8R2
   requirement (§4).

Consequences worth noting:

* **Pin-JTAG (IO39–IO42) is given up.** Those four carry signals instead.
  Debugging uses the ESP32-S3's built-in USB-Serial-JTAG on IO19/IO20, which
  is a better debug path anyway.
* **microSD card-detect is not wired.** No pin was available. Firmware detects
  the card by SPI initialisation instead — a card that fails to respond is
  absent.
* **TMP117 `ALERT` is not wired to a GPIO** — pull-up plus test point only.
  The alert condition is readable over I²C by polling.

Nothing is left floating. Every one of the module's 41 pads is driven,
terminated, or brought to a test point; the ERC enforces this.

---

## 10. Grounding: one net, not split AGND/DGND

Single `GND` net and a single continuous plane. **Deliberately not split** —
see `GROUNDING_NOTES.md` for the full argument. Short version: a split plane
forces return current to detour around the split, and the resulting loop area
usually injects more noise into a high-impedance analog front end than the
split removes. Separation here is achieved by *placement* — the ECG block is
in the opposite corner from the motor driver and the antenna — not by cutting
copper.

An `AGND` supply symbol exists in the library and is intentionally unused, so
that anyone extending the design has to make that decision consciously.

---

## 11. microSD as a module header

**[ARCHITECTURE CHANGE]** `J18` is a 6-way header for a standard SPI microSD
breakout, rather than a microSD socket on the board.

Two reasons: no microSD socket land pattern could be verified from primary
documentation here (they are mechanically fussy — push-pull mechanisms,
shield tabs, card-edge keep-outs); and the architecture diagram itself
describes "a prototype carrier-board architecture using module headers", which
this matches. Pull-ups `R50` (CS) and `R51` (MISO) are 10 kΩ, within the SD
specification's recommended 10 k–100 k.

---

## 12. USB as a header, not a receptacle

**[ARCHITECTURE CHANGE]** `J2` is a 4-way header: `VBUS`, `D−`, `D+`, `GND`.
It feeds the charger and the ESP32-S3's native USB.

A USB-C receptacle would be better, but no USB-C land pattern could be
verified here, and a wrong receptacle footprint makes the board
unprogrammable. A short pigtail to a USB-C breakout works at USB 2.0
full-speed (12 Mbit/s). `J5` (UART: GND, 3V3, TXD0, RXD0, EN, IO0) is the
fallback programming path.

`D+`/`D−` are routed as an adjacent pair but **their differential impedance
has not been calculated** — see `REQUIRES_CONFIRMATION.md`. At full speed over
a few centimetres this is not usually a problem, and the UART header is there
if it is.

---

## 13. Protection — what is present and why each item earns its place

Deliberately not padded. Every protection component below has a specific
failure it prevents.

| Protection | Component | The failure it prevents |
|---|---|---|
| ECG patient current limit | `R18`, `R19`, `R20` = 330 kΩ | Fault current into a human, limited to < 10 µA per the datasheet's own rule |
| Piezo over-voltage | `R41` + `D5`/`D6` | Tens of volts from a piezo film reaching an ADC pin |
| Motor inductive kick | `D7` | Drain of `Q1` flying above `VBAT` at turn-off |
| Buzzer inductive kick | `D8` | Same, for a magnetic buzzer |
| FET fail-safe off | `R44`, `R47` = 100 kΩ | Motor or buzzer running at boot while `IO47`/`IO48` are high-impedance |
| SOS button | `R49` = 1 kΩ series + `C39` = 100 nF | ESD on a user-touchable button; also debounces |
| ADC input drive | `R30` = 1 kΩ + `C22` = 10 nF | ADC sampling glitches on the ECG output |
| Reset integrity | `R7` = 10 kΩ + `C10` = 1 µF | Brown-out mis-boot; `EN` must never float |
| Battery | *external PCM required* | Over-charge / over-discharge / over-current (§1.1) |

**Not added, and why:** no TVS array on the sensor headers (they are inside
the enclosure on short leads, and adding capacitance to the FSR dividers would
degrade them); no reverse-polarity FET on `VBUS` (the TP4056 has internal
reverse blocking — "No blocking diode is required due to the internal PMOSFET
architecture"); no fuse (the required protected pack already provides
over-current cut-off).

---

## 14. Placement and routing strategy

* **Zones follow the architecture diagram's blocks**, one zone per schematic
  sheet, so the board reads like the drawing.
* **ECG is in the far corner from the motor driver and the antenna** —
  the two noise sources it cannot tolerate. Roughly 30 mm from the antenna,
  and separated from the motor block by a plane region.
* **ECG nets are pinned to layer 1** wherever the router could manage it, so
  they sit directly above the layer-2 GND plane with no via discontinuities.
  `DRC_REPORT.md` lists any that needed the bottom layer instead.
* **The module antenna is flush with the top board edge**, with all copper —
  planes included — removed beneath it. Since an EAGLE polygon cannot carry a
  hole, both planes are drawn as an L that omits that corner.
* **Escape channels are reserved as component keep-outs** around the module's
  three pad rows. 36 signals leaving a 1.27 mm pitch need somewhere to go;
  this was the single biggest routing constraint on the board.
* **Fine-pitch parts get a splayed, staggered fan-out** before global routing.
  A 0.5 mm QFN cannot be escaped with a 0.25 mm track, and a via needs ~1.4 mm
  of room, so alternate stubs run on to a second radius.

---

## 15. Things I would do differently with more information

1. **Power-path charger** (MCP73871) instead of the TP4056, removing the
   charge-termination interaction entirely.
2. **Buck-boost regulator** instead of the LDO, so the 3V3 rail holds all the
   way to 3.0 V of cell voltage and the usable capacity increases.
3. **USB-C receptacle** with a verified land pattern.
4. **Relocate the TMP117 to a flex tail.** It is on the main board because
   that is where the architecture puts it, but skin temperature is not
   measurable from inside an electronics pod. A short flex with the TMP117 at
   the far end, against the skin, is the only way that channel means anything.
   The I²C bus is already brought to `J4`, so this is a small change.
5. **Second IMU on the thigh**, as the project's own alternatives list
   suggests, for fall detection with fewer false positives. It needs one more
   I²C address, which the LSM6DSOX's SA0 pin can provide (0x6B) with no board
   change beyond a connector.

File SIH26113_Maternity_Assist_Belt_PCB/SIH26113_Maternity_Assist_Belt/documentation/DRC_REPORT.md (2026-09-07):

<!-- GENERATED by scripts/generate_docs.py from scripts/design.py. Do not edit by hand: re-run the script. -->

# DRC REPORT - SIH26113 Maternity Assist Belt

## How this was produced

`scripts/validate_drc.py` re-parses the emitted `.brd` and measures the real geometry - segment-to-segment and segment-to-pad distances, pad bounding boxes, drill sizes, board-edge and keep-out containment. It deliberately does not share code with the router, so it can contradict it.

> **NOT EXECUTED - TOOL UNAVAILABLE:** Autodesk EAGLE / Fusion Electronics is not installed here, so *EAGLE's* DRC has not been run, and neither has its copper-pour computation. The pours in the `.brd` are declared as polygons; EAGLE calculates their actual shape when the board is opened and `RATSNEST` is executed. Running EAGLE's DRC is step 15 of PCB_BUILD_GUIDE.md.

## Rules checked

| # | Rule |
|---|---|
| D1 | every part's copper is inside the outline with edge clearance |
| D2 | no two component courtyards overlap |
| D3 | nothing (pad, via or track) inside the antenna keep-out |
| D4 | minimum track width and minimum drill |
| D5 | copper clearance, track-to-track and track-to-pad, per layer, with the declared fine-pitch exception applied by region |
| D6 | routing completeness, from the router's own report |
| D7 | every plane-net pad reaches its plane |
| D9 | board-edge clearance for copper |

## Stack-up as emitted

| EAGLE layer | Role | Copper |
|---|---|---|
| 1 (`Top`) | signal + components | 35 um |
| 2 (`Route2`) | GND plane (solid) | 35 um |
| 15 (`Route15`) | 3V3 plane (solid) | 35 um |
| 16 (`Bottom`) | signal | 35 um |

Board outline **100 x 70 mm**, 1.6 mm FR-4, 4 copper layers.

## Clearance rules, and the one declared exception

| Region | Min clearance | Min track |
|---|---|---|
| General | **0.15 mm** | 0.20 mm signal, 0.50 mm power |
| Inside a fine-pitch fan-out (4 regions: AD8232, LSM6DSOX, TMP117, HX711) | **0.127 mm** | 0.15 mm |

The exception is physics, not a fudge: a 0.5 mm-pitch QFN cannot be escaped at 0.15 mm / 0.15 mm - there is not enough room between the pads, which is also why the escape tracks are 0.15 mm rather than 0.20 mm. It applies only inside the named rectangles, `validate_drc.py` enforces it as such, and any pair between 0.10 and 0.15 mm inside one of them is listed as a NOTE below rather than passed silently.

> **The board therefore needs a fabricator offering 5 mil / 0.127 mm trace and gap.** That is a standard option (JLCPCB, PCBWay and most others quote it on 4-layer) but it has to be selected when ordering - see REQUIRES_CONFIRMATION.md.

## Result

```
========================================================================
DRC - SIH26113 Maternity Assist Belt
========================================================================
board        : 100 x 70 mm, 4 layers, 1.6 mm FR-4
rules        : min track 0.15 mm, min drill 0.3 mm, min clearance 0.15 mm general / 0.127 mm inside the 4 declared fine-pitch fan-out regions, edge 0.3 mm

--- ERRORS (4) ---
  E: [D6] net I2C_SDA is not fully routed: left unrouted on purpose: every path the router found came within 0.075 mm of FSR1_ADC on layer 1, below the 0.15 mm rule. Route it by hand in Fusion.
  E: [D6] net SD_CS is not fully routed: left unrouted on purpose: every path the router found came within 0.090 mm of LED_ALERT on layer 1, below the 0.15 mm rule. Route it by hand in Fusion.
  E: [D6] net SD_MISO is not fully routed: left unrouted on purpose: every path the router found came within 0.145 mm of ESP_EN on layer 1, below the 0.15 mm rule. Route it by hand in Fusion.
  E: [D6] net ESP_EN is not fully routed: left unrouted on purpose: every path the router found came within 0.145 mm of PIEZO_ADC on layer 1, below the 0.15 mm rule. Route it by hand in Fusion.

--- WARNINGS (32) ---
  W: [D6] net VBUS: track copper forms 2 groups. This is normal - a multi-drop net reaches each pad separately and the pads join them - and is reported only so a genuinely stranded stub cannot hide among them. Confirm with RATSNEST in Fusion.
  W: [D6] net LED_STDBY_K: track copper forms 2 groups. This is normal - a multi-drop net reaches each pad separately and the pads join them - and is reported only so a genuinely stranded stub cannot hide among them. Confirm with RATSNEST in Fusion.
  W: [D6] net VBAT_SENSE: track copper forms 2 groups. This is normal - a multi-drop net reaches each pad separately and the pads join them - and is reported only so a genuinely stranded stub cannot hide among them. Confirm with RATSNEST in Fusion.
  W: [D6] net ESP_IO0: track copper forms 3 groups. This is normal - a multi-drop net reaches each pad separately and the pads join them - and is reported only so a genuinely stranded stub cannot hide among them. Confirm with RATSNEST in Fusion.
  W: [D6] net UART_RX: track copper forms 2 groups. This is normal - a multi-drop net reaches each pad separately and the pads join them - and is reported only so a genuinely stranded stub cannot hide among them. Confirm with RATSNEST in Fusion.
  W: [D6] net USB_DP: track copper forms 2 groups. This is normal - a multi-drop net reaches each pad separately and the pads join them - and is reported only so a genuinely stranded stub cannot hide among them. Confirm with RATSNEST in Fusion.
  W: [D6] net I2C_SCL: track copper forms 5 groups. This is normal - a multi-drop net reaches each pad separately and the pads join them - and is reported only so a genuinely stranded stub cannot hide among them. Confirm with RATSNEST in Fusion.
  W: [D6] net IMU_INT1: track copper forms 2 groups. This is normal - a multi-drop net reaches each pad separately and the pads join them - and is reported only so a genuinely stranded stub cannot hide among them. Confirm with RATSNEST in Fusion.
  W: [D6] net IMU_INT2: track copper forms 2 groups. This is normal - a multi-drop net reaches each pad separately and the pads join them - and is reported only so a genuinely stranded stub cannot hide among them. Confirm with RATSNEST in Fusion.
  W: [D6] net ANG_SDA: track copper forms 3 groups. This is normal - a multi-drop net reaches each pad separately and the pads join them - and is reported only so a genuinely stranded stub cannot hide among them. Confirm with RATSNEST in Fusion.
  W: [D6] net ANG_SCL: track copper forms 2 groups. This is normal - a multi-drop net reaches each pad separately and the pads join them - and is reported only so a genuinely stranded stub cannot hide among them. Confirm with RATSNEST in Fusion.
  W: [D6] net ECG_RA_F: track copper forms 2 groups. This is normal - a multi-drop net reaches each pad separately and the pads join them - and is reported only so a genuinely stranded stub cannot hide among them. Confirm with RATSNEST in Fusion.
  W: [D6] net ECG_RLD: track copper forms 3 groups. This is normal - a multi-drop net reaches each pad separately and the pads join them - and is reported only so a genuinely stranded stub cannot hide among them. Confirm with RATSNEST in Fusion.
  W: [D6] net ECG_REFIN: track copper forms 2 groups. This is normal - a multi-drop net reaches each pad separately and the pads join them - and is reported only so a genuinely stranded stub cannot hide among them. Confirm with RATSNEST in Fusion.
  W: [D6] net ECG_REFOUT: track copper forms 3 groups. This is normal - a multi-drop net reaches each pad separately and the pads join them - and is reported only so a genuinely stranded stub cannot hide among them. Confirm with RATSNEST in Fusion.
  W: [D6] net ECG_HPSENSE: track copper forms 2 groups. This is normal - a multi-drop net reaches each pad separately and the pads join them - and is reported only so a genuinely stranded stub cannot hide among them. Confirm with RATSNEST in Fusion.
  W: [D6] net ECG_HPDRIVE: track copper forms 2 groups. This is normal - a multi-drop net reaches each pad separately and the pads join them - and is reported only so a genuinely stranded stub cannot hide among them. Confirm with RATSNEST in Fusion.
  W: [D6] net ECG_SW: track copper forms 2 groups. This is normal - a multi-drop net reaches each pad separately and the pads join them - and is reported only so a genuinely stranded stub cannot hide among them. Confirm with RATSNEST in Fusion.
  W: [D6] net ECG_OUT_RAW: track copper forms 2 groups. This is normal - a multi-drop net reaches each pad separately and the pads join them - and is reported only so a genuinely stranded stub cannot hide among them. Confirm with RATSNEST in Fusion.
  W: [D6] net ECG_OUT: track copper forms 2 groups. This is normal - a multi-drop net reaches each pad separately and the pads join them - and is reported only so a genuinely stranded stub cannot hide among them. Confirm with RATSNEST in Fusion.
  W: [D6] net ECG_SDN: track copper forms 3 groups. This is normal - a multi-drop net reaches each pad separately and the pads join them - and is reported only so a genuinely stranded stub cannot hide among them. Confirm with RATSNEST in Fusion.
  W: [D6] net ECG_FR: track copper forms 3 groups. This is normal - a multi-drop net reaches each pad separately and the pads join them - and is reported only so a genuinely stranded stub cannot hide among them. Confirm with RATSNEST in Fusion.
  W: [D6] net ECG_LOD_N: track copper forms 3 groups. This is normal - a multi-drop net reaches each pad separately and the pads join them - and is reported only so a genuinely stranded stub cannot hide among them. Confirm with RATSNEST in Fusion.
  W: [D6] net LC_A_P: track copper forms 2 groups. This is normal - a multi-drop net reaches each pad separately and the pads join them - and is reported only so a genuinely stranded stub cannot hide among them. Confirm with RATSNEST in Fusion.
  W: [D6] net HX_VBG: track copper forms 2 groups. This is normal - a multi-drop net reaches each pad separately and the pads join them - and is reported only so a genuinely stranded stub cannot hide among them. Confirm with RATSNEST in Fusion.
  W: [D6] net HX_XO: track copper forms 2 groups. This is normal - a multi-drop net reaches each pad separately and the pads join them - and is reported only so a genuinely stranded stub cannot hide among them. Confirm with RATSNEST in Fusion.
  W: [D6] net HX_DOUT: track copper forms 3 groups. This is normal - a multi-drop net reaches each pad separately and the pads join them - and is reported only so a genuinely stranded stub cannot hide among them. Confirm with RATSNEST in Fusion.
  W: [D6] net PIEZO_ADC: track copper forms 2 groups. This is normal - a multi-drop net reaches each pad separately and the pads join them - and is reported only so a genuinely stranded stub cannot hide among them. Confirm with RATSNEST in Fusion.
  W: [D6] net BUZZER_EN: track copper forms 3 groups. This is normal - a multi-drop net reaches each pad separately and the pads join them - and is reported only so a genuinely stranded stub cannot hide among them. Confirm with RATSNEST in Fusion.
  W: [D6] net SOS_BTN: track copper forms 2 groups. This is normal - a multi-drop net reaches each pad separately and the pads join them - and is reported only so a genuinely stranded stub cannot hide among them. Confirm with RATSNEST in Fusion.
  W: [D6] net SOS_GPIO: track copper forms 2 groups. This is normal - a multi-drop net reaches each pad separately and the pads join them - and is reported only so a genuinely stranded stub cannot hide among them. Confirm with RATSNEST in Fusion.
  W: [D6] net SD_MOSI: track copper forms 2 groups. This is normal - a multi-drop net reaches each pad separately and the pads join them - and is reported only so a genuinely stranded stub cannot hide among them. Confirm with RATSNEST in Fusion.

--- NOTES (8) ---
  N: [D5] layer 1: SD_MOSI track to pad J12.1 at 0.130 mm - inside a declared fine-pitch fan-out region (0.127 mm rule)
  N: [D5] layer 16: HX_DOUT track to pad J11.1 at 0.130 mm - inside a declared fine-pitch fan-out region (0.127 mm rule)
  N: [D5] minimum wire-pad clearance on layer 1: 0.130 mm
  N: [D5] minimum wire-pad clearance on layer 16: 0.130 mm
  N: [D5] minimum wire-wire clearance on layer 1: 0.154 mm
  N: [D5] minimum wire-wire clearance on layer 16: 0.175 mm
  N: [D5] MEASURED MINIMUM COPPER CLEARANCE ANYWHERE ON THE BOARD: 0.130 mm. This is the number to quote to the fabricator.
  N: [D6] router completed 76 of 80 signal nets

RESULT: FAIL
```

## Routing completeness - stated plainly

- signal nets requiring tracks: **80**
- fully routed by the tool: **76** (95%)
- left as airwires: **4**
- plane nets carried by an inner pour (no tracks needed): **2** (`GND` on layer 2, `3V3` on layer 15)
- tracks emitted: **4523** segments
- vias: **486** total (160 plane-connect, 15 thermal/exposed-pad, the rest from routing)
- fine-pitch fan-out escapes: **45**; coarse-pitch radial stubs: **49**
- **clearance violations, per the independent DRC above: see the D5 error count in the Result block - the DRC re-measures the emitted geometry and is the authoritative number**
- the router's own tally was 4; it uses a slightly more conservative test for which fine-pitch region a pair falls in, so it can flag a pair the DRC clears
- measured minimum copper clearance: quoted in the D5 notes in the Result block above - that is the figure to give the fabricator
- rip-up-and-retry attempts: **1**; orderings tried: **14**, best was seed 8

### Nets deliberately left unrouted to protect clearance

The router prioritises clearance over completeness. Where every path it could find came closer than the rule, it **rips the net out and leaves an airwire** rather than ship a tight gap. An airwire is visible in Fusion the moment the board opens and is a minute's work to route by hand; a 0.09 mm gap is invisible and might reach fabrication.

| Net | Came within | Of | Layer |
|---|---|---|---|
| `I2C_SDA` | 0.075 mm | `FSR1_ADC` | 1 |
| `SD_CS` | 0.090 mm | `LED_ALERT` | 1 |
| `SD_MISO` | 0.145 mm | `ESP_EN` | 1 |
| `ESP_EN` | 0.145 mm | `PIEZO_ADC` | 1 |

### The airwires that remain

These are **not** hidden. Each one appears in Fusion as an airwire the moment the board is opened, and EAGLE's own DRC will list them under "Unrouted". Finishing them by hand with the interactive router is step 13 of PCB_BUILD_GUIDE.md and is unlikely to take more than half an hour: every one of them is a short connection whose two ends are already fanned out.

| Net | Terminal that could not be reached | Reported cause |
|---|---|---|
| `I2C_SDA` | `left unrouted on purpose: every path the router found came within 0.075 mm of FSR1_ADC on layer 1, below the 0.15 mm rule. Route it by hand in Fusion.` | left unrouted on purpose: every path the router found came within 0.075 mm of FSR1_ADC on layer 1, below the 0.15 mm rule. Route it by hand in Fusion. |
| `SD_CS` | `left unrouted on purpose: every path the router found came within 0.090 mm of LED_ALERT on layer 1, below the 0.15 mm rule. Route it by hand in Fusion.` | left unrouted on purpose: every path the router found came within 0.090 mm of LED_ALERT on layer 1, below the 0.15 mm rule. Route it by hand in Fusion. |
| `SD_MISO` | `left unrouted on purpose: every path the router found came within 0.145 mm of ESP_EN on layer 1, below the 0.15 mm rule. Route it by hand in Fusion.` | left unrouted on purpose: every path the router found came within 0.145 mm of ESP_EN on layer 1, below the 0.15 mm rule. Route it by hand in Fusion. |
| `ESP_EN` | `left unrouted on purpose: every path the router found came within 0.145 mm of PIEZO_ADC on layer 1, below the 0.15 mm rule. Route it by hand in Fusion.` | left unrouted on purpose: every path the router found came within 0.145 mm of PIEZO_ADC on layer 1, below the 0.15 mm rule. Route it by hand in Fusion. |

**Why they are hard, and why that is a placement fact rather than a bug.** All of them terminate on a part whose pads are fanned out at 1.2-1.9 mm: the ESP32 module (36 signals escaping a 1.27 mm pitch), the AD8232 (0.5 mm QFN), the LSM6DSOX (0.5 mm LGA) and the HX711 (whose 9 plane pads each take a via right beside the pad). Those are the four most congested spots on the board and they are where a human router also spends their time.

## What has *not* been verified here

| Item | Status |
|---|---|
| EAGLE/Fusion ERC | NOT EXECUTED - TOOL UNAVAILABLE |
| EAGLE/Fusion DRC | NOT EXECUTED - TOOL UNAVAILABLE |
| Copper-pour CONNECTIVITY | MEASURED by scripts/validate_planes.py - it punches an antipad (own radius + the declared 0.4 mm isolate) around every through-hole and via, labels the connected regions, and checks that every plane-net contact lands in the main one. Live figures: pcb/plane_result.json. This check found a real defect - two GND vias outside the pour outline, one of them C7's only path to the ground plane. See FINAL_REVIEW.md. |
| Copper-pour SHAPE, exactly as EAGLE fills it | NOT COMPUTED - EAGLE calculates polygons on load. Every plane-net **pad** is given its own plane via, so pad connectivity does not depend on the pour shape. Run RATSNEST - build guide step 14. |
| Gerber / drill output | NOT GENERATED - needs EAGLE's CAM processor |
| 3D / mechanical interference | NOT CHECKED - no 3D models are attached to these footprints |
| Impedance of the USB pair | CALCULATED - see USB_PAIR_ANALYSIS.md. As-routed ~165 ohm differential, not the 90 ohm USB 2.0 asks for, because the two nets were routed as ordinary signals (0.806 mm closest gap = 2.24x the dielectric height, so they are effectively uncoupled). Not a functional risk: the ESP32-S3 USB is Full Speed only, and 44 mm at 5.8 ps/mm is electrically short by 2.6x against the fastest 4 ns edge USB FS permits. |

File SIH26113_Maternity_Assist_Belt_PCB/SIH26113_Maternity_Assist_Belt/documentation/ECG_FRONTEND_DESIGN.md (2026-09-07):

# ECG ANALOG FRONT END — DESIGN NOTE

> **This is not a medical device.** It is a prototype heart-rate channel for
> engineering evaluation. It has no galvanic isolation, no defibrillation
> protection, and no regulatory compliance work behind it. Read
> `REQUIRES_CONFIRMATION.md` item B2 before connecting it to a person.

The architecture diagram says "3 electrodes → AD8232 → ESP32 ADC". That is a
block, not a circuit. This note is the circuit, and why each value is what it
is.

Every value below traces to the *AD8232 Data Sheet Rev. A*. Where a value was
designed rather than copied, the arithmetic is shown.

---

## Signal chain

```
   J7.1 LA ──[R18 330k]──┬──────────────► +IN  (pin 2)
                         └──[R21 10M]──► +VS      (DC leads-off bias)

   J7.2 RA ──[R19 330k]──┬──────────────► −IN  (pin 3)
                         └──[R22 10M]──► +VS      (DC leads-off bias)

   J7.3 RL ◄─[R20 330k]───────────────── RLD  (pin 5)
                                          └──[C17 1n]── RLDFB (pin 4)

                   ┌──────────── AD8232 ────────────┐
   in-amp gain 100 │  IAOUT (19) ─┐                 │
                   │              │  two-pole HPF   │
   HPDRIVE (1) ──[C18 220n]──► HPSENSE (20)         │   pole 1: 7.2 Hz
   HPSENSE (20) ──[R25 10M]──► IAOUT (19)           │
   IAOUT (19) ──[C19 220n]──► SW (6)                │   pole 2: 0.72 Hz
   SW (6) ──[R26 1M]──► REFOUT (8)                  │
                   └─────────────────────────────────┘
                          │
                          ▼  SW node = HPF output
             ──[R27 470k]──┬──► OPAMP+ (7)              pole: ~41 Hz
                        [C20 8n2]
                           └──► REFOUT

             OPAMP− (9) ──[R28 100k]──► REFOUT          gain = 1 + 1M/100k = 11
             OPAMP− (9) ──[R29 1M]────► OUT (10)
             OPAMP− (9) ──[C21 3n9]───► OUT (10)        pole: 40.8 Hz

             OUT (10) ──[R30 1k]──┬──► ECG_OUT ──► ESP32 IO1 (ADC1_CH0)
                               [C22 10n]
                                  └──► GND

   Reference:  3V3 ──[R23 10M]──┬── REFIN (18)   →  REFOUT (8) = 1.65 V
                                │
               GND ──[R24 10M]──┤
                                │
                             [C16 100n]
                                │
                               GND

   Supply:     3V3 ──┬──[C23 100n]──GND   (at pin 17)
                     └──[C24 1u]────GND

   Control:    SDN  (13) ── ECG_SDN   ← IO37, R31 100k pull-up  → enabled
               FR   (15) ── ECG_FR    ← IO39, R32 100k pull-down → disabled
               AC/DC(14) ── GND                                  → DC leads-off
               LOD+ (12) ── ECG_LOD_P → IO35
               LOD− (11) ── ECG_LOD_N → IO36
               EP        ── GND (4 thermal vias)
```

---

## Supply rail — the one decision that can destroy the part

**The AD8232's absolute maximum supply is 3.5 V.** It is on the regulated
**3V3** rail and never sees `VBAT`, which reaches 4.2 V while charging.

The datasheet is explicit: *"It can also operate from rechargeable lithium-ion
batteries, but the designer must take into account that the voltage during a
charge cycle may exceed the absolute maximum ratings of the AD8232. To avoid
damage to the part, use a power switch or a low power, low dropout
regulator."*

The architecture diagram does not say which rail feeds it. Wiring it to `VBAT`
would work on the bench and destroy the part the first time someone plugged in
a charger.

---

## Patient protection — 330 kΩ, and why not the datasheet's 180 kΩ

The datasheet's example circuits (Figures 62, 64, 66) all show 180 kΩ series
resistors. Its *Input Protection* text says something stricter:

> *"As a safety measure, place a resistor between the input pin and the
> electrode that is connected to the subject to ensure that the current flow
> never exceeds 10 µA. Calculate the value of this resistor to be equal to the
> supply voltage across the AD8232 divided by 10 µA."*

3.3 V / 10 µA = **330 kΩ**. The 180 kΩ figures correspond to the 5 mA
continuous-current limit the part itself can survive, not the 10 µA
subject-safety rule. For a wearable in contact with a pregnant woman, the
stricter number is the right one, so `R18`, `R19` and `R20` are all 330 kΩ.

For the driven electrode the datasheet gives the same number independently:
*"if the supply used is 3.0 V, this resistor should be greater than 330 kΩ to
account for component and supply variations."* — hence `R20` = 330 kΩ.

Cost of the choice: 330 kΩ against the in-amp's 10 kΩ input resistance is a
small gain error, and it raises source impedance slightly. Both are
irrelevant next to a factor-of-1.8 improvement in fault-current limiting.

---

## Three-electrode configuration with DC leads-off

Per datasheet Figure 50 and the *DC Leads Off Detection* section:

* `R21`, `R22` (10 MΩ) pull `+IN` and `−IN` up to `+VS`;
* `AC/DC` (pin 14) is tied to **GND**, selecting DC mode — *"To use this mode,
  connect the AC/DC pin to ground."*
* the third electrode is driven by `RLD`, which is what keeps the subject
  inside the in-amp's common-mode range.

The advantage of DC mode over AC mode is per-electrode reporting: *"it is
possible to indicate which electrode is disconnected"*, via `LOD+` and `LOD−`
separately. Both go to GPIOs, so the app can say *"the left electrode has come
off"* rather than just *"signal lost"* — worth two pins on a wearable that a
user puts on themselves.

## Right-leg drive

Datasheet Figure 46 and the *Right Leg Drive Amplifier* section: the inverting
input of A2 is fed internally from the common-mode signal through a 150 kΩ
resistor, so the only external component needed is the integrator capacitor.

*"An integrator can be built by connecting a capacitor between the RLD FB and
RLD terminals. A good starting point is a 1 nF capacitor, which places the
crossover frequency at about 1 kHz... This configuration results in about
26 dB of loop gain available at a frequency range from 50 Hz to 60 Hz for
common-mode line rejection."*

`C17` = **1 nF**, exactly that. 26 dB of mains rejection at 50 Hz is the
single most useful thing this circuit does for a device used near mains
wiring.

---

## Reference / virtual ground

Datasheet Figure 47. `R23`/`R24` = 10 MΩ each from `3V3` and `GND` set `REFIN`
to mid-supply; the internal buffer presents it on `REFOUT`, which is the
analog reference for the whole signal chain.

*"To limit the power consumption of the voltage divider, the use of large
resistors is recommended, such as 10 MΩ... use a capacitor in parallel with
the lower resistor on the divider for additional filtering."*

`C16` = 100 nF does that filtering. The consequence has to be respected:

> Settling time = 5 × (R23 ∥ R24) × C16 = 5 × 5 MΩ × 100 nF = **2.5 seconds**

**Firmware must wait 2.5 s after power-up — and after leaving `SDN` shutdown —
before the first reading means anything.** The datasheet notes that shutdown
does not discharge this capacitor, so a wake from shutdown settles faster in
practice, but 2.5 s is the number to design to.

Total divider current: 3.3 V / 20 MΩ = 165 nA. Negligible even in deep sleep.

---

## High-pass filter — two poles, and the factor of 100

The DC-blocking amplifier is not an ordinary RC. Its corner is *"100 times
higher than is typically expected from a single-pole filter"* because *"the
typical filter cutoff equation is modified by the gain of 100 of the
instrumentation amplifier"*:

```
                 100
    f_-3dB  =  ─────────
               2π · R · C
```

Getting this wrong by 100× is an easy mistake, so both poles are shown
worked out:

**Pole 1** — the DC-blocking integrator (`C18` between `HPDRIVE` and
`HPSENSE`, `R25` between `HPSENSE` and `IAOUT`):

```
    f1 = 100 / (2π × 10 MΩ × 220 nF) = 100 / 13.82 = 7.2 Hz
```

**Pole 2** — passive AC coupling at the in-amp output (`C19` from `IAOUT` to
`SW`, `R26` from `SW` to `REFOUT`). This one is an ordinary RC, no factor of
100:

```
    f2 = 1 / (2π × 1 MΩ × 220 nF) = 0.72 Hz
```

Topology is datasheet Figure 55. Note that `C19`'s far side goes to the **`SW`
pin**, not straight to the filter output: *"Note that the right side of C2
connects to the SW terminal."* `SW` is the fast-restore switch terminal, and
routing the AC-coupling network through it lets the internal 10 kΩ path shunt
`R26` during fast restore, cutting the recovery time.

### Sanity check against the datasheet's own examples

| Datasheet circuit | Stated corner | Components | Check |
|---|---|---|---|
| Fig. 62, single pole | 7 Hz | 10 MΩ, 0.22 µF | 100/(2π·10M·0.22µ) = 7.24 Hz ✓ |
| Fig. 64, two poles | 7 Hz | 10 MΩ + 0.22 µF, 100 kΩ + 0.22 µF | 7.24 Hz and 7.24 Hz ✓ |
| **This design** | **7.2 / 0.72 Hz** | 10 MΩ + 220 nF, 1 MΩ + 220 nF | as above |

The formula reproduces the datasheet's own numbers, which is the point of
checking it.

---

## Low-pass filter and gain — designed, not copied

The datasheet's example circuits use a Sallen-Key here. This design uses two
cascaded single poles instead, for two reasons the datasheet itself raises:

1. A Sallen-Key configured for a gain of 11 has a Q that depends on component
   ratios and can peak or oscillate with real tolerances.
2. *"if this passive network is not buffered, it exhibits higher output
   impedance at the input of a subsequent low-pass filter, such as with
   Sallen-Key filter topologies."* The two-pole HPF ahead of it is exactly
   such an unbuffered network.

The cascade is unconditionally stable and its response is trivially
predictable.

**Pole A** — series `R27` into `OPAMP+`, `C20` to `REFOUT`:

```
    f_A = 1 / (2π × 470 kΩ × 8.2 nF) = 41.3 Hz
```

**Pole B** — `C21` across the feedback resistor `R29`:

```
    f_B = 1 / (2π × 1 MΩ × 3.9 nF) = 40.8 Hz
```

**Gain** — non-inverting, referenced to `REFOUT`:

```
    G = 1 + R29/R28 = 1 + 1 MΩ/100 kΩ = 11
```

**Total system gain = 100 (in-amp) × 11 = 1100.**

### The source-impedance interaction, accounted for

The HPF's output impedance at 20 Hz is roughly `R26` in parallel with `C19`'s
reactance:

```
    X_C19 (20 Hz) = 1/(2π × 20 × 220n) = 36 kΩ
    Z_out ≈ 1 MΩ ∥ 36 kΩ ≈ 35 kΩ
```

That adds to `R27`, moving pole A:

```
    f_A' = 1 / (2π × (470k + 35k) × 8.2n) = 38.4 Hz
```

A 7 % shift, in the harmless direction. `R27` was chosen large (470 kΩ) partly
so this interaction stays small — a 100 kΩ resistor there would have shifted
the pole by 35 %.

---

## Resulting response and dynamic range

| | Value |
|---|---|
| Pass band | ≈ **7 – 40 Hz** |
| Roll-off below 7 Hz | 40 dB/decade to 0.72 Hz, 20 dB/decade below |
| Roll-off above 40 Hz | 40 dB/decade |
| Total gain in band | **1100** |
| Output centre | `REFOUT` = 1.65 V |
| Input 0.1 mV pk-pk (weak abdominal) | 110 mV pk-pk → 1.595 – 1.705 V |
| Input 1.0 mV pk-pk (strong) | 1.1 V pk-pk → 1.10 – 2.20 V |
| ESP32-S3 ADC1, 12 dB attenuation | 0 – 3.1 V |

Both cases sit comfortably inside the ADC range with margin at each rail, so
the signal never clips and the reading stays linear.

Recommended sampling: **250 Hz**. That is 6× the 40 Hz corner, and the
40 dB/decade roll-off puts anything above 125 Hz (the Nyquist limit) more than
20 dB down before `R30`/`C22` add further attenuation.

---

## Why the pass band is narrow — the honest trade-off

7–40 Hz is deliberately narrower than diagnostic ECG (0.05–150 Hz). This is
the central design trade in the whole subsystem, so it is stated plainly.

The datasheet distinguishes its own configurations:

* **Cardiac Monitor (Fig. 66, 0.5 Hz HPF / 40 Hz LPF)** — *"designed for
  monitoring the shape of the ECG waveform. It assumes that the patient
  remains relatively still during the measurement, and therefore, motion
  artifacts are less of an issue."*
* **Exercise / HR at the hands (Fig. 64, 7 Hz HPF / 24 Hz LPF)** — for a
  moving subject, and *"only suitable to determine the heart rate, and not to
  analyze the ECG signal characteristics."*

A belt worn by a walking pregnant woman is the second case, not the first. The
project needs **maternal heart rate and trends**, so motion-artefact rejection
is worth more than waveform fidelity.

**So: this is a heart-rate channel, not a diagnostic ECG.** It will give
reliable beat detection and HR variability on a moving subject. It will *not*
give clinically interpretable ST segments or P-wave morphology, and nothing in
this project should claim otherwise.

### If you want to move toward waveform monitoring

All the filter components are 0805 and reworkable:

| Change | Effect |
|---|---|
| `C18`, `C19` → 2.2 µF | HPF poles to 0.72 Hz and 0.072 Hz — approaches the datasheet's cardiac-monitor response, but needs physically large capacitors at high-impedance nodes, which brings its own leakage problems |
| Better: adopt datasheet **Figure 56** (three extra components, `R_COMP` = 0.14 × R1) | *"allows lower cutoff frequency with lower R and C values"* — the topology ADI themselves use for the 0.5 Hz cardiac monitor |
| `C20` → 2.2 nF, `C21` → 1 nF | LPF to ~150 Hz |
| — | expect to fight motion artefact in firmware instead: adaptive filtering keyed off the LSM6DSOX, which is already on the board and is exactly what the project's own notes propose |

---

## Layout compliance

The datasheet's *Layout Recommendations* section, item by item:

| Requirement | What the board does |
|---|---|
| *"Keep all of the connections between high impedance nodes as short as possible"* | `ECG_HPSENSE`, `ECG_IAOUT`, `ECG_SW`, `ECG_REFIN`, `ECG_REFOUT` all stay inside Zone 3 with their passives placed against `U7`'s fan-out |
| *"keep the input traces symmetrical and length matched"* | `R18` and `R19` are placed symmetrically about the `+IN`/`−IN` axis, same orientation, same distance |
| *"Place safety and input bias resistors in the same position relative to each input"* | `R18`/`R19` (safety) and `R21`/`R22` (bias) are mirror-image pairs |
| *"the use of a ground plane significantly improves the noise rejection"* | Layer 2 is a solid, unbroken GND plane 0.36 mm below the ECG tracks. Not split — see `GROUNDING_NOTES.md` |
| *"Place a 0.1 µF capacitor close to the supply pin. A 1 µF capacitor can be used farther away"* | `C23` = 100 nF adjacent to pin 17, `C24` = 1 µF nearby |

Plus, from the architecture diagram's own note ("keep analog path short /
quiet"):

* `U7` is in the opposite corner of the board from the motor driver
  (Zone 6) and roughly 45 mm from the module antenna;
* the electrode connector `J7` is on the right board edge immediately beside
  `U7`, so the unprotected high-impedance run is about 5 mm;
* ECG nets are pinned to layer 1 wherever the router managed it, so they sit
  directly over the plane with no via discontinuities. Any that had to use
  layer 16 are listed in `DRC_REPORT.md`.

---

## Firmware requirements this circuit imposes

1. **Wait 2.5 s** after power-up, or after releasing `SDN`, before trusting a
   reading. The `REFIN` network needs it.
2. **Sample `IO1` (ADC1_CH0) at 250 Hz.** Use ADC1 — ADC2 is unusable while
   the radio is on.
3. **Read `LOD+` (`IO35`) and `LOD−` (`IO36`) before every measurement.**
   Either high means an electrode is off and the data is meaningless. Report
   *which* one to the user.
4. **Drive `FR` (`IO39`) high for ~100 ms after attaching electrodes**, then
   low. This is what fast restore is for — without it the filters take
   several seconds to settle after the step.
5. **Pull `SDN` (`IO37`) low between measurements** to save ~170 µA. Remember
   the 2.5 s settling on wake.
6. **Do not run the vibration motor while sampling ECG.** The board separates
   them physically and the loop is kept small, but a motor is a motor. Gate
   the two in firmware.
7. **Expect a mains-frequency residual.** RLD gives ~26 dB of rejection at
   50/60 Hz; the 40 Hz low-pass gives more. If it is still visible, a notch in
   firmware is cheaper than a board change.

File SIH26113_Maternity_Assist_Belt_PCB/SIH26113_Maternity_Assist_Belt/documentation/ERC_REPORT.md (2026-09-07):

<!-- GENERATED by scripts/generate_docs.py from scripts/design.py. Do not edit by hand: re-run the script. -->

# ERC REPORT - SIH26113 Maternity Assist Belt

## How this was produced

`scripts/validate_erc.py` runs eleven rule groups against the same design model that generates the `.sch`, so every finding below is genuinely present in the schematic. It is **not** Autodesk EAGLE's own ERC.

> **NOT EXECUTED - TOOL UNAVAILABLE:** EAGLE / Fusion Electronics is not installed in the environment where these files were produced, so *EAGLE's* ERC has not been run. Running it is step 6 of PCB_BUILD_GUIDE.md. The independent check below is what can be claimed today.

## Rules checked

| # | Rule |
|---|---|
| R1 | reference designators unique; every deviceset exists in the library |
| R2 | every (part, pin) in the netlist names a pin that exists |
| R3 | every pin of every part is on exactly one net - no floating pins, no pin on two nets |
| R4 | no net has fewer than two connections, except declared no-connects |
| R5 | every net feeding a power pin also carries a supply symbol |
| R6 | no net has two or more push-pull outputs |
| R7 | no net has inputs but no driver |
| R8 | each I2C line has exactly one pull-up; no address clash on a bus |
| R9 | ESP32-S3: analog only on ADC1; strapping pins flagged; every module pin in the GPIO table |
| R10 | MOSFET gates have a pull-down; inductive loads have a correctly-oriented flyback diode; clamp polarity |
| R11 | every LED has a series resistor |

## Result

```
========================================================================
ERC - SIH26113 Maternity Assist Belt
========================================================================
parts            : 167
nets             : 84
pins in design   : 420
net connections  : 420

--- ERRORS (0) ---

--- WARNINGS (0) ---

--- NOTES (7) ---
  N: [R4] LDO_NC: intentional single-pin net - AP2112 pin 4 is 'No Connection' per Diodes DS39724 Rev.2-2. Left unconnected deliberately.
  N: [R4] IMU_OCS_AUX: intentional single-pin net - LSM6DSOX DS12814 Rev.4 Table 1 note 2: 'Leave pin electrically unconnected and soldered to PCB.' Its own pad satisfies both halves of that instruction.
  N: [R8] SENSOR (I2C0): addresses J4=0x36, U4=0x48, U5=0x6A
  N: [R8] ANGLE  (I2C1): addresses U6=0x36
  N: [R8] 0x36 is used on BOTH busses (MAX17048 breakout on the sensor bus, AS5600 on the angle bus). This is the deliberate resolution of the fixed-address clash - they are electrically separate busses.
  N: [R10] Q1: flyback D7 present on MOTOR_N
  N: [R10] Q2: flyback D8 present on BUZZ_N

RESULT: PASS
```

## Intentional exceptions

| Item | Why it is acceptable |
|---|---|
| `LDO_NC` is a single-pin net | AP2112 pin 4 is documented as "No Connection" (Diodes DS39724 Rev.2-2). Leaving it unconnected is the datasheet's own instruction. Declared explicitly in `validate_erc.py` rather than silenced. |
| `IMU_OCS_AUX` goes only to test point TP7 | The LSM6DSOX datasheet (DS12814 Rev.4, Table 1 note 2) says to leave OCS_Aux *electrically* unconnected but soldered to the board. An isolated land satisfies both halves of that instruction, and it is not a floating input on a net with a driver. |
| `TMP_ALERT` goes to a pull-up and a test point, not to a GPIO | The pin budget has no spare GPIO. TMP117 alerts are readable over I2C by polling the configuration register, so the hardware ALERT line is a convenience, not a requirement. |
| `AS_OUT`, `AS_PGO`, `HX_BASE`, `HX_XO` go to test points | All four are datasheet-designated "NC when not used" or optional-function pins. Bringing them to a land keeps them probeable without committing a GPIO. |
| `0x36` appears on both I2C busses | This is the resolution of a real conflict, not an oversight - see DESIGN_ASSUMPTIONS.md. The AS5600 and the MAX17048 both have a fixed 0x36 address and are therefore put on physically separate busses. |

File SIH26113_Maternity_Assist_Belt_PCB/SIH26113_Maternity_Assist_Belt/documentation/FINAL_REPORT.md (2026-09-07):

<!-- GENERATED by scripts/gen_reports.py from scripts/design.py plus the router and DRC output. Do not edit by hand: re-run the script. -->

# FINAL REPORT - SIH26113 Maternity Assist Belt

> **NOT A MEDICAL DEVICE.** Prototype for engineering evaluation. The ECG channel is not isolated and the board carries no battery protection circuit. Read `REQUIRES_CONFIRMATION.md` items B1 and B2 before applying power.

## 1. What was created

A complete Autodesk EAGLE 9 / Fusion Electronics project for the SIH26113 Maternity Assist Belt carrier board: a component library with every pinout verified against the manufacturer's datasheet, a seven-sheet schematic, a placed and routed four-layer board, 12 renders drawn from those files, and 18 documents.

Everything is generated from one source model (`scripts/design.py`), so the library, schematic, board, netlist, GPIO table, BOM and reports cannot disagree with each other. The generators verify themselves: `generate_schematic.py` re-parses its own output and asserts the netlist matches the model exactly, and `generate_board.py` does the same for elements and signals.

## 2. Exact files generated

| Path | What it is |
|---|---|
| [`libraries/SIH26113_Maternity_Assist_Belt.lbr`](../libraries/SIH26113_Maternity_Assist_Belt.lbr) | EAGLE 9 library: 23 footprints, 28 symbols, 30 devices |
| [`schematic/SIH26113_Maternity_Assist_Belt.sch`](../schematic/SIH26113_Maternity_Assist_Belt.sch) | 7 sheets, 167 parts, 84 nets |
| [`pcb/SIH26113_Maternity_Assist_Belt.brd`](../pcb/SIH26113_Maternity_Assist_Belt.brd) | 4-layer board, 100 x 70 mm |
| [`pcb/route_report.json`](../pcb/route_report.json) | the router's own output, machine-readable |
| [`pcb/drc_result.json`](../pcb/drc_result.json) | DRC findings, machine-readable |
| [`documentation/COMPONENT_VERIFICATION.md`](./COMPONENT_VERIFICATION.md) | every pinout and footprint with its source |
| [`documentation/DESIGN_ASSUMPTIONS.md`](./DESIGN_ASSUMPTIONS.md) | every decision, and the 7 architecture changes |
| [`documentation/ECG_FRONTEND_DESIGN.md`](./ECG_FRONTEND_DESIGN.md) | the AD8232 circuit, with the arithmetic |
| [`documentation/GROUNDING_NOTES.md`](./GROUNDING_NOTES.md) | why one ground plane and not a split |
| [`documentation/POWER_BUDGET.md`](./POWER_BUDGET.md) | itemised current budget and dropout analysis |
| [`documentation/GPIO_ASSIGNMENT.md`](./GPIO_ASSIGNMENT.md) | all 41 module pins [generated] |
| [`documentation/NETLIST.md`](./NETLIST.md) | every net, source, load and routing state [generated] |
| [`documentation/BOM.md`](./BOM.md) | bill of materials [generated] |
| [`documentation/BOM.csv`](./BOM.csv) | bill of materials, machine-readable [generated] |
| [`documentation/ERC_REPORT.md`](./ERC_REPORT.md) | rules, result and declared exceptions [generated] |
| [`documentation/DRC_REPORT.md`](./DRC_REPORT.md) | rules, result, clearance and airwires [generated] |
| [`documentation/MANUFACTURING_CHECK.md`](./MANUFACTURING_CHECK.md) | the 19-point pre-fabrication check [generated] |
| [`documentation/PROJECT_STATISTICS.md`](./PROJECT_STATISTICS.md) | counts and metrics [generated] |
| [`documentation/FINAL_REVIEW.md`](./FINAL_REVIEW.md) | 27-point independent design review |
| [`documentation/PCB_BUILD_GUIDE.md`](./PCB_BUILD_GUIDE.md) | 20 steps, Fusion to fabrication |
| [`documentation/REQUIRES_CONFIRMATION.md`](./REQUIRES_CONFIRMATION.md) | open items, worst first |
| [`documentation/FINAL_REPORT.md`](./FINAL_REPORT.md) | this document [generated] |
| [`renders/schematic_p1.png`](../renders/schematic_p1.png) | sheet 1 - power entry, charging, 3V3 |
| [`renders/schematic_p2.png`](../renders/schematic_p2.png) | sheet 2 - ESP32-S3 core |
| [`renders/schematic_p3.png`](../renders/schematic_p3.png) | sheet 3 - I2C sensors |
| [`renders/schematic_p4.png`](../renders/schematic_p4.png) | sheet 4 - ECG analog front end |
| [`renders/schematic_p5.png`](../renders/schematic_p5.png) | sheet 5 - mechanical sensing |
| [`renders/schematic_p6.png`](../renders/schematic_p6.png) | sheet 6 - FET-driven alerts |
| [`renders/schematic_p7.png`](../renders/schematic_p7.png) | sheet 7 - user input and storage |
| [`renders/pcb_top.png`](../renders/pcb_top.png) | layer 1 copper, pads, silkscreen |
| [`renders/pcb_bottom.png`](../renders/pcb_bottom.png) | layer 16 copper, mirrored |
| [`renders/pcb_layers.png`](../renders/pcb_layers.png) | all four copper layers overlaid |
| [`renders/pcb_assembly.png`](../renders/pcb_assembly.png) | placement, designators and zones |
| [`renders/pcb_3d.png`](../renders/pcb_3d.png) | isometric mechanical envelope |
| [`scripts/`](../scripts/) | the 13 generators, routers and validators that produce all of the above |

## 3 & 4. Exact components and variants used

Every pinout below was read from the manufacturer's datasheet; the citation for each is in [`COMPONENT_VERIFICATION.md`](./COMPONENT_VERIFICATION.md).

| Ref | Exact part | Manufacturer | Package | Why this variant |
|---|---|---|---|---|
| `U1` | **TP4056-42-SOP8-PP** | NanJing Top Power | `SOIC-8-N` | SOP-8 is hand-solderable and the datasheet gives R_PROG directly; charge set to 500 mA, not 1 A, because this footprint has no thermal land |
| `U2` | **AP2112K-3.3** | - | `SOT-23-5` | 600 mA guaranteed minimum against a 510 mA worst case, and an LDO rather than a switcher because the ECG front end is 20 mm away |
| `U3` | **ESP32-S3-WROOM-1-N8R2** | Espressif Systems | `ESP32-S3-WROOM-1` | **-N8R2 is mandatory** - octal-PSRAM variants reserve IO35/36/37, which this design uses |
| `U4` | **TMP117AIDRVR** | Texas Instruments | `WSON-6-DRV0006B` | WSON (DRV) is the only variant in production; TI publish its land pattern |
| `U5` | **LSM6DSOXTR** | STMicroelectronics | `LGA-14L-2.5X3.0` | LGA-14, I2C mode 1, address 0x6A (SA0 to GND) |
| `U6` | **AS5600-ASOM** | ams-OSRAM | `SOIC-8-N` | SOIC-8 - by far the easiest fine-position sensor to assemble; address 0x36 is fixed, which forced the second I2C bus |
| `U7` | **AD8232ACPZ-R7** | Analog Devices | `LFCSP-20-4X4-P050` | **supply 2.0-3.5 V only**, so it is on 3V3 and never on VBAT |
| `U8` | **HX711** | Avia Semiconductor | `SOP-16-N` | SOP-16, ratiometric to AVDD so sharing the 3V3 rail costs nothing; RATE grounded for 10 Hz |
| `Q1`, `Q2` | AO3400A (or pin-compatible logic-level N-FET) | Alpha & Omega | `SOT-23-3` | V_GS(th) low enough for 3.3 V drive |
| `D5`-`D8` | 1N5819HW | generic | `SOD-123` | 40 V / 1 A Schottky for flyback and piezo clamping |
| `J1`, `J8` | S2B-PH-K-S / S4B-PH-K-S | JST | `JST-PH-2/4` | PCB hole ø0.7 +0.1 mm read from JST's own board-layout figure |

Full line-item list with quantities: [`BOM.md`](./BOM.md) / [`BOM.csv`](./BOM.csv).

## 5. Unresolved components

| Item | State | Where it is recorded |
|---|---|---|
| **MAX17048 fuel gauge** | **not placed.** Datasheet unreachable from this environment, so neither pinout nor land pattern could be verified. Replaced by header `J4` for a breakout, plus a 470k/470k VBAT divider on `IO9` that works either way | `REQUIRES_CONFIRMATION.md` H1 |
| **Li-Po protection (DW01A + FS8205A)** | **not placed.** Pinouts unverifiable; a protected cell/pack is required at `J1` instead | H1 / **B1 (BLOCKING)** |
| **Stretch sensor** | not selected. `R37` = 10 k is an explicit **placeholder** - the correct value is the geometric mean of the chosen sensor's resistance band | H2 |
| **Load cell** | not selected. Bridge resistance and mV/V sensitivity unknown | H3 |
| **Vibration motor** | not selected. Voltage rating decides whether `R45` stays at 0 R | **B3 (BLOCKING)** |
| **Buzzer** | active-magnetic assumed; passive piezo works on the same circuit with PWM | M3 |
| **Piezo film, FSRs, electrodes, hall switch** | not selected; FSR dividers sized for an FSR402-class part | M4 / `DESIGN_ASSUMPTIONS.md` 7.1 |
| **Tactile switches** | standard 6.5 x 4.5 mm grid assumed; confirm the vendor part | H4 |

## 6. Important design assumptions

Full reasoning in [`DESIGN_ASSUMPTIONS.md`](./DESIGN_ASSUMPTIONS.md). The seven that **depart from the architecture diagram** are marked.

| # | Assumption / decision | Why |
|---|---|---|
| 1 | **[CHANGE]** No battery protection on the board - a protected cell/pack is required | DW01A + FS8205A pinouts could not be verified, and guessing on a lithium protection circuit is not acceptable |
| 2 | **[CHANGE]** Four layers, not two: signal / GND plane / 3V3 plane / signal | Measured: on two layers the router finished ~50 of 81 nets and the reachable copper split into disconnected regions. The AD8232 amplifies a sub-millivolt signal by 1100 and its datasheet asks for a ground plane |
| 3 | **[CHANGE]** Two I2C busses, not one | AS5600 and MAX17048 are **both fixed at 0x36**. The diagram's single bus cannot work |
| 4 | **[CHANGE]** MAX17048 replaced by a breakout header plus a VBAT divider | datasheet unreachable; see section 5 |
| 5 | **[CHANGE]** Two discrete LEDs instead of an RGB | an RGB needs 3 GPIOs (none spare) and an addressable one needs >= 3.5 V, which the 3V3 rail cannot supply |
| 6 | **[CHANGE]** microSD as a 6-way module header | no socket land pattern could be verified, and the diagram itself describes 'module headers' |
| 7 | **[CHANGE]** USB as a 4-way header, not a receptacle | no USB-C land pattern could be verified; a wrong receptacle makes the board unprogrammable |
| 8 | AD8232 on **3V3 only** | absolute maximum 3.5 V; VBAT reaches 4.2 V while charging |
| 9 | All 8 analog signals on **ADC1** (GPIO1-10) | ADC2 is unusable while the radio is active |
| 10 | **-N8R2 module mandatory** | octal-PSRAM variants reserve IO35/36/37 |
| 11 | One ground net, one continuous plane - **no AGND/DGND split** | 8 signals cross the analog/digital boundary; one bridge cannot serve them, and a track crossing a plane split is the very failure mode a split is meant to avoid |
| 12 | ECG pass band ~7-40 Hz, gain 1100 | the datasheet's motion-artefact configuration - a belt on a walking subject is not a resting patient. **A heart-rate channel, not diagnostic ECG** |
| 13 | Charge current 500 mA (`R1` = 2.4 k), not 1 A | halves the linear charger's dissipation; the SOP-8 footprint has no thermal land |
| 14 | FSR dividers 10 k | geometric mean of the 2 k-100 k band, so the output spans 0.30-2.75 V without clipping |
| 15 | Clearance beats completeness | where the router could only finish a net by breaking the clearance rule it leaves an airwire instead. An airwire is visible; a 0.05 mm gap is not |

## 7. ERC status

**PASS - 0 errors, 0 warnings.** `scripts/validate_erc.py`, 11 rule groups, run against the same model that generates the `.sch`. 167 parts, 84 nets, 420 pin connections, and every pin on exactly one net - no floating pins, no pin on two nets.

Declared exceptions, each with the datasheet sentence that justifies it, are in [`ERC_REPORT.md`](./ERC_REPORT.md).

> **Autodesk EAGLE / Fusion's own ERC: NOT EXECUTED - TOOL UNAVAILABLE.** No EAGLE installation existed where these files were produced. Running it is step 6 of the build guide, where the exceptions you should expect to approve are pre-listed.

## 8. DRC status

**Geometry is clean: 0 clearance, width, drill, placement, keep-out or board-edge violations.**

- **measured minimum copper clearance anywhere on the board: 0.130 mm** - the figure to quote to the fabricator
- minimum track 0.15 mm (fine-pitch escapes only), minimum drill 0.30 mm
- the 4 reported errors are all *unrouted nets*, not geometry faults - see section 13

> **Autodesk EAGLE / Fusion's own DRC: NOT EXECUTED - TOOL UNAVAILABLE**, and neither is its copper-pour computation. Every plane-net *pad* has its own dedicated via, so pad connectivity does not depend on the pour. Build guide steps 14-15.

Rules, per-layer minima and every finding: [`DRC_REPORT.md`](./DRC_REPORT.md).

## 9. Number of nets

**84 nets**, 420 pin connections.

- 2 carried by an inner plane (`GND` on layer 2, `3V3` on layer 15) - no tracks needed
- 80 needing tracks, of which **76 routed (95 %)**
- 2 declared single-pin no-connects (`LDO_NC`, `IMU_OCS_AUX`), each with a datasheet citation

Per-net detail: [`NETLIST.md`](./NETLIST.md).

## 10. Number of components

**150 placements** (167 schematic parts - the difference is 17 supply-rail symbols, which are not physical parts).

- 8 ICs and modules
- 18 connectors, 3 switches, 8 diodes and LEDs, 2 MOSFETs
- 88 passives, 19 test points, 4 mounting holes
- **409 pads** on the board in total

Line items and quantities: [`BOM.md`](./BOM.md) / [`BOM.csv`](./BOM.csv).

## 11. PCB dimensions

**100 x 70 mm** (70 cm2), 1.6 mm FR-4.

Tallest part is 8.5 mm (a 2.54 mm header with a mated crimp housing), so budget about 11.6 mm of internal enclosure height. Mounting holes: 4 x M2 at (3, 3), (97, 3), (2.6, 42), (97, 67) - note `H3` is mid-left-edge rather than a corner, because the top-left corner falls inside the antenna keep-out.

Envelope render: [`renders/pcb_3d.png`](../renders/pcb_3d.png). Full pre-fabrication check: [`MANUFACTURING_CHECK.md`](./MANUFACTURING_CHECK.md).

## 12. Layer count

**4 copper layers**, EAGLE layer setup `(1*2*15*16)`.

| Layer | Role |
|---|---|
| 1 (`Top`) | signal + components |
| 2 (`Route2`) | GND plane (solid) |
| 15 (`Route15`) | 3V3 plane (solid) |
| 16 (`Bottom`) | signal |

Both plane polygons are drawn as an **L** that omits the antenna corner: Espressif require no copper - planes included - beneath the module antenna, and an EAGLE polygon cannot carry a hole.
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

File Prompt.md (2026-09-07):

I am attaching the PCB architecture image to this conversation.

You have access to the project directory and should inspect all existing files before starting.

Create a New Sub folder under the Repo with a similar naming structure and work inside it for this work, nothing should be done outside for this work.

Do not create the deliverables only as explanations in chat. Create the actual files in the project directory.

Use your terminal/file tools extensively. You are expected to generate, inspect, modify and validate the project files yourself.

If a required EDA operation cannot be performed in your environment, create the appropriate source/script/output that can be executed in Autodesk Fusion and explicitly tell me what could not be executed.

Also Create a Readme of what you did and whats happening and everything A to Z for this PCB thing.

MASTER PROMPT — SIH26113 MATERNITY ASSIST BELT
PCB LIBRARY + SCHEMATIC + PCB DESIGN + DOCUMENTATION

You are acting as a senior electronics engineer, PCB designer, embedded hardware engineer, EDA library engineer, and autonomous engineering agent.

I am developing a prototype called:

SIH26113 — Maternity Assist Belt

I have provided an image showing the intended PCB architecture. Treat that architecture image as the starting point, but DO NOT blindly assume that every component, pinout, package, electrical characteristic, or connection shown in the image is technically correct.

Your job is to turn this architecture into a professional, manufacturable prototype PCB design workflow for Autodesk Fusion Electronics / EAGLE-compatible files.

IMPORTANT:
This is an engineering task, not a visual mockup.

The final result must prioritize:
1. Electrical correctness
2. Correct manufacturer pinouts
3. Correct component packages
4. Correct footprints
5. Correct schematic connectivity
6. ERC/DRC compatibility
7. Manufacturability
8. Clear documentation
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

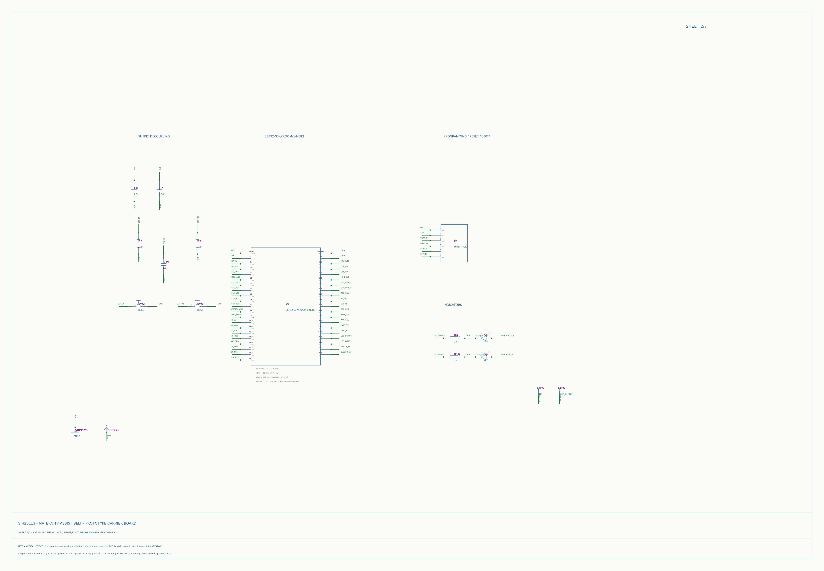
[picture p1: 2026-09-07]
SIH26113_Maternity_Assist_Belt_PCB/SIH26113_Maternity_Assist_Belt/renders/schematic_p2.png

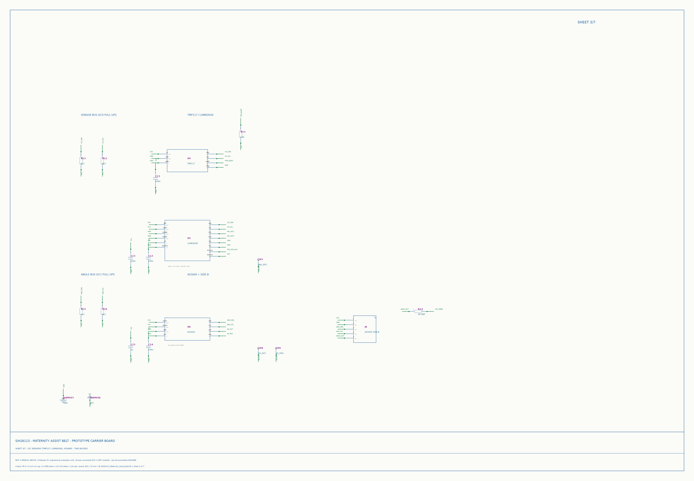
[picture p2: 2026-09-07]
SIH26113_Maternity_Assist_Belt_PCB/SIH26113_Maternity_Assist_Belt/renders/schematic_p3.png

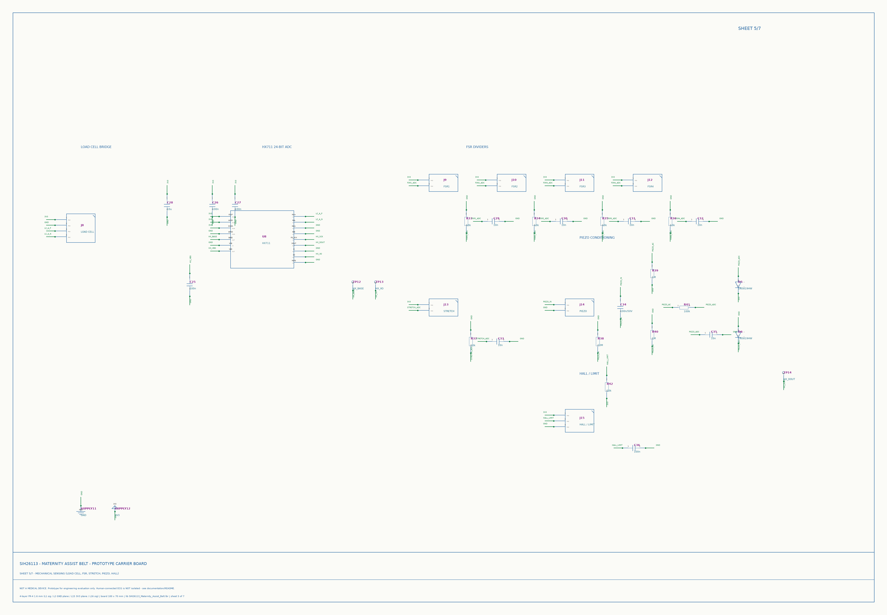
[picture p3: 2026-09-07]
SIH26113_Maternity_Assist_Belt_PCB/SIH26113_Maternity_Assist_Belt/renders/schematic_p5.png

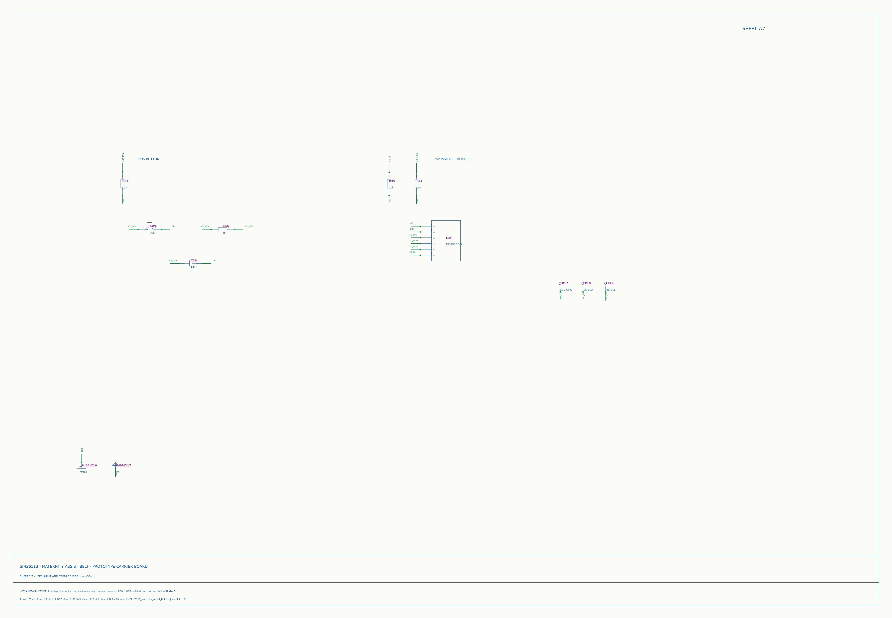
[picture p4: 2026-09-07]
SIH26113_Maternity_Assist_Belt_PCB/SIH26113_Maternity_Assist_Belt/renders/schematic_p7.png

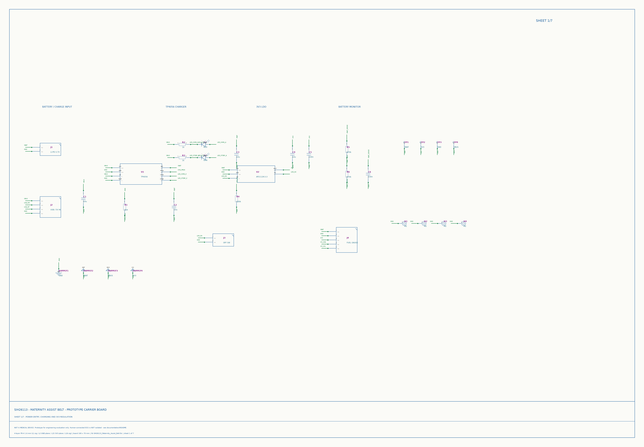
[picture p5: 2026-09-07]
SIH26113_Maternity_Assist_Belt_PCB/SIH26113_Maternity_Assist_Belt/renders/schematic_p1.png

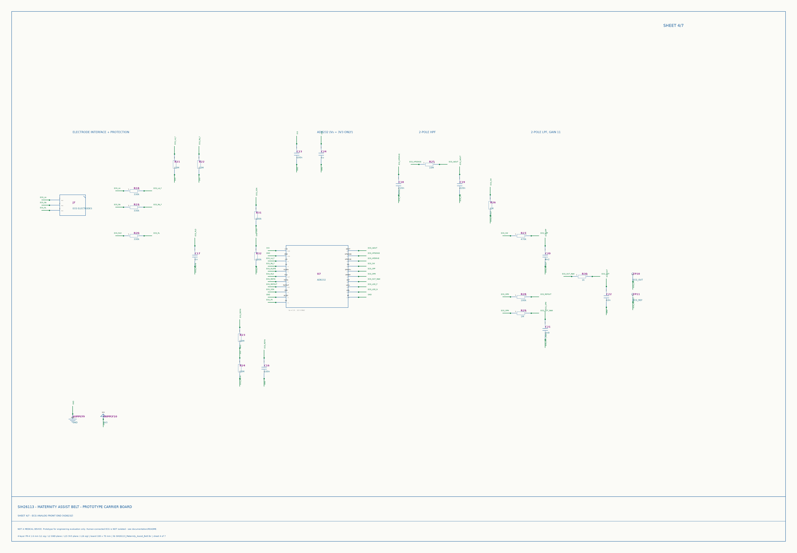
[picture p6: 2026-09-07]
SIH26113_Maternity_Assist_Belt_PCB/SIH26113_Maternity_Assist_Belt/renders/schematic_p4.png

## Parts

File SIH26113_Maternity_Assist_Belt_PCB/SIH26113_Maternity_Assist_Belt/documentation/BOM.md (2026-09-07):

<!-- GENERATED by scripts/generate_docs.py from scripts/design.py. Do not edit by hand: re-run the script. -->

# BILL OF MATERIALS - SIH26113 Maternity Assist Belt

**75 line items, 150 placements.** Board: 100 x 70 mm, 4-layer FR-4 1.6 mm, 1 oz copper.

Supplier part numbers are deliberately absent: they were not verified in this environment, and a fabricated SKU is worse than no SKU. Manufacturer part numbers below were taken from the datasheet ordering guides cited in COMPONENT_VERIFICATION.md.

Blank MPN = a generic passive or connector where any part meeting the value and package is acceptable, or a part still to be selected (see REQUIRES_CONFIRMATION.md).

`BOM.csv` carries three further columns - **Supplier**, **Supplier PN** and **Lifecycle** - deliberately left empty. Distributor stock and lifecycle status could not be checked from the environment these files were produced in, and an invented SKU or an unverified "Active" is worse than a blank field. Fill them in from your own distributor.

| Ref | Qty | Value | Manufacturer | MPN | Description | Package |
|---|---|---|---|---|---|---|
| C1 C2 C3 C4 C28 C37 C38 | 7 | 10u |  |  | Chip capacitor, 0805 (2012 metric) | `C0805` |
| C10 C15 C24 | 3 | 1u |  |  | Chip capacitor, 0805 (2012 metric) | `C0805` |
| C17 | 1 | 1n |  |  | Chip capacitor, 0805 (2012 metric) | `C0805` |
| C18 C19 | 2 | 220n |  |  | Chip capacitor, 0805 (2012 metric) | `C0805` |
| C20 | 1 | 8n2 |  |  | Chip capacitor, 0805 (2012 metric) | `C0805` |
| C21 | 1 | 3n9 |  |  | Chip capacitor, 0805 (2012 metric) | `C0805` |
| C22 C29 C30 C31 C32 C33 C35 | 7 | 10n |  |  | Chip capacitor, 0805 (2012 metric) | `C0805` |
| C34 | 1 | 100n/50V |  |  | Chip capacitor, 0805 (2012 metric) | `C0805` |
| C5 C6 C7 C11 C12 C13 C14 C16 C23 C25 C26 C27 C36 C39 | 14 | 100n |  |  | Chip capacitor, 0805 (2012 metric) | `C0805` |
| C8 | 1 | 22u |  |  | Chip capacitor, 0805 (2012 metric) | `C0805` |
| D1 D4 | 2 | RED |  |  | Chip LED, 0805 | `LED0805` |
| D2 D3 | 2 | GRN |  |  | Chip LED, 0805 | `LED0805` |
| D5 D6 D7 D8 | 4 | 1N5819HW | generic (Diodes/onsemi/MDD) | 1N5819HW | Schottky/rectifier diode, SOD-123 | `SOD-123` |
| H1 H2 H3 H4 | 4 | M2 |  |  | M2 plated mounting hole, GND-stitched | `MOUNT-M2` |
| J1 | 1 | LI-PO 3.7V | JST | S2B-PH-K-S | JST PH 2 | `JST-PH-2` |
| J10 | 1 | FSR2 | - | FSR402 + 1x2 header | 1x2 2 | `HDR-1X2` |
| J11 | 1 | FSR3 | - | FSR402 + 1x2 header | 1x2 2 | `HDR-1X2` |
| J12 | 1 | FSR4 | - | FSR402 + 1x2 header | 1x2 2 | `HDR-1X2` |
| J13 | 1 | STRETCH | - | TBD - see REQUIRES_CONFIRMATION.md | 1x2 2 | `HDR-1X2` |
| J14 | 1 | PIEZO | - | piezo film + 1x2 header | 1x2 2 | `HDR-1X2` |
| J15 | 1 | HALL / LIMIT | - | generic 1x3 2.54mm header | 1x3 2 | `HDR-1X3` |
| J16 | 1 | VIB MOTOR | - | generic 1x2 2.54mm header | 1x2 2 | `HDR-1X2` |
| J17 | 1 | BUZZER | - | generic 1x2 2.54mm header | 1x2 2 | `HDR-1X2` |
| J18 | 1 | MICROSD SPI | - | generic microSD SPI breakout + 1x6 header | 1x6 2 | `HDR-1X6` |
| J2 | 1 | USB / 5V IN | - | generic 1x4 2.54mm header | 1x4 2 | `HDR-1X4` |
| J3 | 1 | OFF SW | - | generic 1x2 2.54mm header | 1x2 2 | `HDR-1X2` |
| J4 | 1 | FUEL GAUGE | - | generic 1x5 2.54mm header | 1x5 2 | `HDR-1X5` |
| J5 | 1 | UART PROG | - | generic 1x6 2.54mm header | 1x6 2 | `HDR-1X6` |
| J6 | 1 | AS5600 SIDE-B | - | generic 1x5 2.54mm header | 1x5 2 | `HDR-1X5` |
| J7 | 1 | ECG ELECTRODES | - | generic 1x3 2.54mm header | 1x3 2 | `HDR-1X3` |
| J8 | 1 | LOAD CELL | JST | S4B-PH-K-S | JST PH 2 | `JST-PH-4` |
| J9 | 1 | FSR1 | - | FSR402 + 1x2 header | 1x2 2 | `HDR-1X2` |
| Q1 Q2 | 2 | AO3400A | Alpha & Omega Semiconductor | AO3400A | N-channel logic-level MOSFET, SOT-23-3 | `SOT-23-3` |
| R1 | 1 | 2k4 |  |  | Chip resistor, 0805 (2012 metric) | `R0805` |
| R11 R12 R15 R16 | 4 | 4k7 |  |  | Chip resistor, 0805 (2012 metric) | `R0805` |
| R17 | 1 | 0R DNP |  |  | Chip resistor, 0805 (2012 metric) | `R0805` |
| R18 R19 R20 | 3 | 330k |  |  | Chip resistor, 0805 (2012 metric) | `R0805` |
| R2 R3 R9 R10 R30 R49 | 6 | 1k |  |  | Chip resistor, 0805 (2012 metric) | `R0805` |
| R21 R22 R23 R24 R25 R38 | 6 | 10M |  |  | Chip resistor, 0805 (2012 metric) | `R0805` |
| R26 R29 R39 R40 | 4 | 1M |  |  | Chip resistor, 0805 (2012 metric) | `R0805` |
| R4 R28 R31 R32 R41 R44 R47 | 7 | 100k |  |  | Chip resistor, 0805 (2012 metric) | `R0805` |
| R43 R46 | 2 | 100R |  |  | Chip resistor, 0805 (2012 metric) | `R0805` |
| R45 | 1 | 0R |  |  | Chip resistor, 0805 (2012 metric) | `R0805` |
| R5 R6 R27 | 3 | 470k |  |  | Chip resistor, 0805 (2012 metric) | `R0805` |
| R7 R8 R13 R33 R34 R35 R36 R37 R42 R48 R50 R51 | 12 | 10k |  |  | Chip resistor, 0805 (2012 metric) | `R0805` |
| SW2 | 1 | RESET | - | TL1105 family | 6 x 6 mm through-hole tactile push-button | `TACT-6X6-THT` |
| SW3 | 1 | BOOT | - | TL1105 family | 6 x 6 mm through-hole tactile push-button | `TACT-6X6-THT` |
| SW4 | 1 | SOS | - | TL1105 family | 6 x 6 mm through-hole tactile push-button | `TACT-6X6-THT` |
| TP1 | 1 | VBAT |  |  | 1 | `TESTPOINT-1.5` |
| TP10 | 1 | ECG_OUT |  |  | 1 | `TESTPOINT-1.5` |
| TP11 | 1 | ECG_REF |  |  | 1 | `TESTPOINT-1.5` |
| TP12 | 1 | HX_BASE |  |  | 1 | `TESTPOINT-1.5` |
| TP13 | 1 | HX_XO |  |  | 1 | `TESTPOINT-1.5` |
| TP14 | 1 | HX_DOUT |  |  | 1 | `TESTPOINT-1.5` |
| TP15 | 1 | MOTOR_EN |  |  | 1 | `TESTPOINT-1.5` |
| TP16 | 1 | BUZZER_EN |  |  | 1 | `TESTPOINT-1.5` |
| TP17 | 1 | SOS_GPIO |  |  | 1 | `TESTPOINT-1.5` |
| TP18 | 1 | I2C_SDA |  |  | 1 | `TESTPOINT-1.5` |
| TP19 | 1 | I2C_SCL |  |  | 1 | `TESTPOINT-1.5` |
| TP2 | 1 | 3V3 |  |  | 1 | `TESTPOINT-1.5` |
| TP3 | 1 | GND |  |  | 1 | `TESTPOINT-1.5` |
| TP4 | 1 | VBUS |  |  | 1 | `TESTPOINT-1.5` |
| TP5 | 1 | IO3 |  |  | 1 | `TESTPOINT-1.5` |
| TP6 | 1 | TMP_ALERT |  |  | 1 | `TESTPOINT-1.5` |
| TP7 | 1 | IMU_INT1 |  |  | 1 | `TESTPOINT-1.5` |
| TP8 | 1 | AS_OUT |  |  | 1 | `TESTPOINT-1.5` |
| TP9 | 1 | AS_PGO |  |  | 1 | `TESTPOINT-1.5` |
| U1 | 1 | TP4056 | NanJing Top Power | TP4056-42-SOP8-PP | NanJing Top Power TP4056-42-SOP8-PP 1 A standalone linear Li-ion charger, 4 | `SOIC-8-N` |
| U2 | 1 | AP2112K-3.3 |  |  | Diodes AP2112K-3 | `SOT-23-5` |
| U3 | 1 | ESP32-S3-WROOM-1-N8R2 | Espressif Systems | ESP32-S3-WROOM-1-N8R2 | Espressif ESP32-S3-WROOM-1-N8R2 | `ESP32-S3-WROOM-1` |
| U4 | 1 | TMP117 | Texas Instruments | TMP117AIDRVR | TI TMP117AIDRVR high-accuracy digital temperature sensor, WSON-6 (DRV) | `WSON-6-DRV0006B` |
| U5 | 1 | LSM6DSOX | STMicroelectronics | LSM6DSOXTR | ST LSM6DSOXTR 6-axis IMU (3-axis accel + 3-axis gyro), LGA-14L | `LGA-14L-2.5X3.0` |
| U6 | 1 | AS5600 | ams-OSRAM | AS5600-ASOM | ams-OSRAM AS5600-ASOM 12-bit contactless magnetic rotary position sensor, SOIC-8 | `SOIC-8-N` |
| U7 | 1 | AD8232 | Analog Devices | AD8232ACPZ-R7 | Analog Devices AD8232ACPZ-R7 single-lead heart-rate monitor front end | `LFCSP-20-4X4-P050` |
| U8 | 1 | HX711 | Avia Semiconductor | HX711 | Avia Semiconductor HX711 24-bit ADC for bridge sensors, SOP-16L | `SOP-16-N` |

## Placements by package

| Package | Count | Assembly |
|---|---|---|
| `R0805` | 50 | hand-solderable |
| `C0805` | 38 | hand-solderable |
| `TESTPOINT-1.5` | 19 | n/a (bare land) |
| `HDR-1X2` | 9 | through-hole, hand-solderable |
| `LED0805` | 4 | hand-solderable |
| `MOUNT-M2` | 4 | n/a (mechanical) |
| `SOD-123` | 4 | hand-solderable |
| `TACT-6X6-THT` | 3 | through-hole, hand-solderable |
| `SOIC-8-N` | 2 | hand-solderable |
| `HDR-1X5` | 2 | through-hole, hand-solderable |
| `HDR-1X6` | 2 | through-hole, hand-solderable |
| `HDR-1X3` | 2 | through-hole, hand-solderable |
| `SOT-23-3` | 2 | hand-solderable |
| `JST-PH-2` | 1 | through-hole, hand-solderable |
| `HDR-1X4` | 1 | through-hole, hand-solderable |
| `SOT-23-5` | 1 | hand-solderable |
| `ESP32-S3-WROOM-1` | 1 | reflow or hot air (castellated, 1.27 mm) |
| `WSON-6-DRV0006B` | 1 | reflow / hot air only (0.65 mm + thermal pad) |
| `LGA-14L-2.5X3.0` | 1 | reflow / hot air only (0.5 mm LGA) |
| `LFCSP-20-4X4-P050` | 1 | reflow / hot air only (0.5 mm QFN + exposed pad) |
| `SOP-16-N` | 1 | hand-solderable |
| `JST-PH-4` | 1 | through-hole, hand-solderable |

## Assembly note

Three parts cannot be soldered with an iron: the AD8232 (0.5 mm-pitch QFN with a 2.5 mm exposed pad), the LSM6DSOX (0.5 mm LGA) and the TMP117 (0.65 mm WSON with a thermal pad). They need a stencil and a hotplate/reflow oven, or hot air with paste. Everything else on the board is 0805, SOT-23, SOIC/SOP-1.27 or through-hole, all of which are comfortable by hand.

## Parts NOT on this board

| Function | Why it is off-board |
|---|---|
| MAX17048 fuel gauge | Its data sheet could not be retrieved in this environment, so its land pattern could not be verified. Provided as header `J4` for an off-the-shelf breakout, plus an always-available resistor-divider battery measurement on `IO9`. See REQUIRES_CONFIRMATION.md. |
| Li-Po protection (DW01A + FS8205A) | A **protected** cell/pack is required at `J1` instead. Bare protection ICs were not added because their pinouts could not be verified from primary documentation, and guessing on a battery-protection circuit is not acceptable. |
| microSD socket | Implemented as a 6-way header (`J18`) for a standard SPI breakout module, matching the architecture diagram's 'module headers' approach and avoiding an unverified socket land pattern. |
| Load cell, FSRs, stretch sensor, piezo film, motor, buzzer, electrodes | Off-board transducers on flying leads. |

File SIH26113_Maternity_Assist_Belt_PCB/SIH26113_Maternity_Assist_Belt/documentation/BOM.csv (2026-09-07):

Reference | Qty | Value | Manufacturer | MPN | Description | Package | Supplier | Supplier PN | Lifecycle | Library device | Notes
C1 C2 C3 C4 C28 C37 C38 | 7 | 10u |  |  | Chip capacitor, 0805 (2012 metric) | C0805 |  |  |  | C-0805 | VBUS input bulk
C10 C15 C24 | 3 | 1u |  |  | Chip capacitor, 0805 (2012 metric) | C0805 |  |  |  | C-0805 | EN RC delay (power-on reset)
C17 | 1 | 1n |  |  | Chip capacitor, 0805 (2012 metric) | C0805 |  |  |  | C-0805 | RLD integrator (RLDFB to RLD)
C18 C19 | 2 | 220n |  |  | Chip capacitor, 0805 (2012 metric) | C0805 |  |  |  | C-0805 | HPF pole 1 cap (HPDRIVE to HPSENSE)
C20 | 1 | 8n2 |  |  | Chip capacitor, 0805 (2012 metric) | C0805 |  |  |  | C-0805 | LPF input cap -> ~41 Hz pole
C21 | 1 | 3n9 |  |  | Chip capacitor, 0805 (2012 metric) | C0805 |  |  |  | C-0805 | Feedback cap -> ~41 Hz pole (2nd LPF pole)
C22 C29 C30 C31 C32 C33 C35 | 7 | 10n |  |  | Chip capacitor, 0805 (2012 metric) | C0805 |  |  |  | C-0805 | ADC input reservoir
C34 | 1 | 100n/50V |  |  | Chip capacitor, 0805 (2012 metric) | C0805 |  |  |  | C-0805 | Piezo AC coupling (must withstand the film's open-circuit transient)
C5 C6 C7 C11 C12 C13 C14 C16 C23 C25 C26 C27 C36 C39 | 14 | 100n |  |  | Chip capacitor, 0805 (2012 metric) | C0805 |  |  |  | C-0805 | LDO output HF bypass
C8 | 1 | 22u |  |  | Chip capacitor, 0805 (2012 metric) | C0805 |  |  |  | C-0805 | ESP32 3V3 bulk (Wi-Fi TX current burst)
D1 D4 | 2 | RED |  |  | Chip LED, 0805 | LED0805 |  |  |  | LED-0805 | Charging indicator
D2 D3 | 2 | GRN |  |  | Chip LED, 0805 | LED0805 |  |  |  | LED-0805 | Charge-complete indicator
D5 D6 D7 D8 | 4 | 1N5819HW | generic (Diodes/onsemi/MDD) | 1N5819HW | Schottky/rectifier diode, SOD-123 | SOD-123 |  |  |  | DIODE-SOD123 | Piezo over-voltage clamp to 3V3
H1 H2 H3 H4 | 4 | M2 |  |  | M2 plated mounting hole, GND-stitched | MOUNT-M2 |  |  |  | MOUNTHOLE-M2 | M2 mounting hole, GND-stitched
J1 | 1 | LI-PO 3.7V | JST | S2B-PH-K-S | JST PH 2 | JST-PH-2 |  |  |  | JST-PH-2 | Li-Po cell input (protected pack required)
J10 | 1 | FSR2 | - | FSR402 + 1x2 header | 1x2 2 | HDR-1X2 |  |  |  | HDR-1X2 | Force-sensing resistor 2 (belt pressure)
J11 | 1 | FSR3 | - | FSR402 + 1x2 header | 1x2 2 | HDR-1X2 |  |  |  | HDR-1X2 | Force-sensing resistor 3 (belt pressure)
J12 | 1 | FSR4 | - | FSR402 + 1x2 header | 1x2 2 | HDR-1X2 |  |  |  | HDR-1X2 | Force-sensing resistor 4 (belt pressure)
J13 | 1 | STRETCH | - | TBD - see REQUIRES_CONFIRMATION.md | 1x2 2 | HDR-1X2 |  |  |  | HDR-1X2 | Abdominal stretch / extension sensor
J14 | 1 | PIEZO | - | piezo film + 1x2 header | 1x2 2 | HDR-1X2 |  |  |  | HDR-1X2 | Piezo film fetal-movement sensor
J15 | 1 | HALL / LIMIT | - | generic 1x3 2.54mm header | 1x3 2 | HDR-1X3 |  |  |  | HDR-1X3 | Hall or mechanical limit switch (rail travel)
J16 | 1 | VIB MOTOR | - | generic 1x2 2.54mm header | 1x2 2 | HDR-1X2 |  |  |  | HDR-1X2 | Vibration motor output
J17 | 1 | BUZZER | - | generic 1x2 2.54mm header | 1x2 2 | HDR-1X2 |  |  |  | HDR-1X2 | Magnetic or piezo buzzer output
J18 | 1 | MICROSD SPI | - | generic microSD SPI breakout + 1x6 header | 1x6 2 | HDR-1X6 |  |  |  | HDR-1X6 | microSD breakout module (SPI)
J2 | 1 | USB / 5V IN | - | generic 1x4 2.54mm header | 1x4 2 | HDR-1X4 |  |  |  | HDR-1X4 | 5 V charge input + ESP32-S3 native USB D+/D-
J3 | 1 | OFF SW | - | generic 1x2 2.54mm header | 1x2 2 | HDR-1X2 |  |  |  | HDR-1X2 | External latching switch: closed = board OFF
J4 | 1 | FUEL GAUGE | - | generic 1x5 2.54mm header | 1x5 2 | HDR-1X5 |  |  |  | HDR-1X5 | MAX17048 breakout header (I2C, addr 0x36)
J5 | 1 | UART PROG | - | generic 1x6 2.54mm header | 1x6 2 | HDR-1X6 |  |  |  | HDR-1X6 | Fallback UART programming header
J6 | 1 | AS5600 SIDE-B | - | generic 1x5 2.54mm header | 1x5 2 | HDR-1X5 |  |  |  | HDR-1X5 | Second AS5600 (angle bus B + analog OUT)
J7 | 1 | ECG ELECTRODES | - | generic 1x3 2.54mm header | 1x3 2 | HDR-1X3 |  |  |  | HDR-1X3 | LA / RA / RL electrode leads
J8 | 1 | LOAD CELL | JST | S4B-PH-K-S | JST PH 2 | JST-PH-4 |  |  |  | JST-PH-4 | 4-wire bridge: E+, E-, A+, A-
J9 | 1 | FSR1 | - | FSR402 + 1x2 header | 1x2 2 | HDR-1X2 |  |  |  | HDR-1X2 | Force-sensing resistor 1 (belt pressure)
Q1 Q2 | 2 | AO3400A | Alpha & Omega Semiconductor | AO3400A | N-channel logic-level MOSFET, SOT-23-3 | SOT-23-3 |  |  |  | NMOS-SOT23 | Low-side switch for the vibration motor
R1 | 1 | 2k4 |  |  | Chip resistor, 0805 (2012 metric) | R0805 |  |  |  | R-0805 | TP4056 PROG: sets 500 mA charge current
R11 R12 R15 R16 | 4 | 4k7 |  |  | Chip resistor, 0805 (2012 metric) | R0805 |  |  |  | R-0805 | I2C_SDA pull-up (bus A)
R17 | 1 | 0R DNP |  |  | Chip resistor, 0805 (2012 metric) | R0805 |  |  |  | R-0805 | Opt-in link: side-B AS5600 analog OUT -> IO3. Leave unpopulated unless the analog path is used (IO3 is a strapping pin).
R18 R19 R20 | 3 | 330k |  |  | Chip resistor, 0805 (2012 metric) | R0805 |  |  |  | R-0805 | LA patient-protection series R (Vs/10uA)
R2 R3 R9 R10 R30 R49 | 6 | 1k |  |  | Chip resistor, 0805 (2012 metric) | R0805 |  |  |  | R-0805 | CHRG LED current limit
R21 R22 R23 R24 R25 R38 | 6 | 10M |  |  | Chip resistor, 0805 (2012 metric) | R0805 |  |  |  | R-0805 | LA DC leads-off bias pull-up
R26 R29 R39 R40 | 4 | 1M |  |  | Chip resistor, 0805 (2012 metric) | R0805 |  |  |  | R-0805 | HPF pole 2 resistor (SW to REFOUT) -> 0.72 Hz
R4 R28 R31 R32 R41 R44 R47 | 7 | 100k |  |  | Chip resistor, 0805 (2012 metric) | R0805 |  |  |  | R-0805 | LDO EN pull-up to VBAT
R43 R46 | 2 | 100R |  |  | Chip resistor, 0805 (2012 metric) | R0805 |  |  |  | R-0805 | Motor gate series resistor (slew limit)
R45 | 1 | 0R |  |  | Chip resistor, 0805 (2012 metric) | R0805 |  |  |  | R-0805 | Motor ballast: populate only if the chosen motor is rated below 4.2 V
R5 R6 R27 | 3 | 470k |  |  | Chip resistor, 0805 (2012 metric) | R0805 |  |  |  | R-0805 | VBAT sense divider, upper
R7 R8 R13 R33 R34 R35 R36 R37 R42 R48 R50 R51 | 12 | 10k |  |  | Chip resistor, 0805 (2012 metric) | R0805 |  |  |  | R-0805 | EN pull-up
SW2 | 1 | RESET | - | TL1105 family | 6 x 6 mm through-hole tactile push-button | TACT-6X6-THT |  |  |  | SW-TACT-6MM | Reset button (pulls EN low)
SW3 | 1 | BOOT | - | TL1105 family | 6 x 6 mm through-hole tactile push-button | TACT-6X6-THT |  |  |  | SW-TACT-6MM | Boot button (pulls IO0 low)
SW4 | 1 | SOS | - | TL1105 family | 6 x 6 mm through-hole tactile push-button | TACT-6X6-THT |  |  |  | SW-TACT-6MM | Manual emergency SOS button
TP1 | 1 | VBAT |  |  | 1 | TESTPOINT-1.5 |  |  |  | TESTPOINT | Test point: VBAT
TP10 | 1 | ECG_OUT |  |  | 1 | TESTPOINT-1.5 |  |  |  | TESTPOINT | Test point: conditioned ECG output
TP11 | 1 | ECG_REF |  |  | 1 | TESTPOINT-1.5 |  |  |  | TESTPOINT | Test point: AD8232 REFOUT virtual ground
TP12 | 1 | HX_BASE |  |  | 1 | TESTPOINT-1.5 |  |  |  | TESTPOINT | HX711 BASE (regulator unused: NC)
TP13 | 1 | HX_XO |  |  | 1 | TESTPOINT-1.5 |  |  |  | TESTPOINT | HX711 XO (crystal unused: NC)
TP14 | 1 | HX_DOUT |  |  | 1 | TESTPOINT-1.5 |  |  |  | TESTPOINT | Test point: HX711 serial data out
TP15 | 1 | MOTOR_EN |  |  | 1 | TESTPOINT-1.5 |  |  |  | TESTPOINT | Test point: MOTOR_EN gate drive
TP16 | 1 | BUZZER_EN |  |  | 1 | TESTPOINT-1.5 |  |  |  | TESTPOINT | Test point: BUZZER_EN gate drive
TP17 | 1 | SOS_GPIO |  |  | 1 | TESTPOINT-1.5 |  |  |  | TESTPOINT | Test point: SOS GPIO
TP18 | 1 | I2C_SDA |  |  | 1 | TESTPOINT-1.5 |  |  |  | TESTPOINT | Test point: sensor-bus SDA
TP19 | 1 | I2C_SCL |  |  | 1 | TESTPOINT-1.5 |  |  |  | TESTPOINT | Test point: sensor-bus SCL
TP2 | 1 | 3V3 |  |  | 1 | TESTPOINT-1.5 |  |  |  | TESTPOINT | Test point: 3V3
TP3 | 1 | GND |  |  | 1 | TESTPOINT-1.5 |  |  |  | TESTPOINT | Test point: GND
TP4 | 1 | VBUS |  |  | 1 | TESTPOINT-1.5 |  |  |  | TESTPOINT | Test point: VBUS
TP5 | 1 | IO3 |  |  | 1 | TESTPOINT-1.5 |  |  |  | TESTPOINT | Test point: IO3 spare / ANG2_OUT
TP6 | 1 | TMP_ALERT |  |  | 1 | TESTPOINT-1.5 |  |  |  | TESTPOINT | Test point: TMP117 ALERT (not routed to a GPIO)
TP7 | 1 | IMU_INT1 |  |  | 1 | TESTPOINT-1.5 |  |  |  | TESTPOINT | Test point: IMU interrupt 1
TP8 | 1 | AS_OUT |  |  | 1 | TESTPOINT-1.5 |  |  |  | TESTPOINT | AS5600 analog/PWM OUT (unused, I2C is used)
TP9 | 1 | AS_PGO |  |  | 1 | TESTPOINT-1.5 |  |  |  | TESTPOINT | AS5600 PGO programming pin (internal pull-up)
U1 | 1 | TP4056 | NanJing Top Power | TP4056-42-SOP8-PP | NanJing Top Power TP4056-42-SOP8-PP 1 A standalone linear Li-ion charger, 4 | SOIC-8-N |  |  |  | TP4056 | 1 A linear Li-ion charger, 4.2 V float
U2 | 1 | AP2112K-3.3 |  |  | Diodes AP2112K-3 | SOT-23-5 |  |  |  | AP2112K-3.3 | 600 mA LDO, 3.3 V fixed
U3 | 1 | ESP32-S3-WROOM-1-N8R2 | Espressif Systems | ESP32-S3-WROOM-1-N8R2 | Espressif ESP32-S3-WROOM-1-N8R2 | ESP32-S3-WROOM-1 |  |  |  | ESP32-S3-WROOM-1 | Central MCU: Xtensa LX7 dual core, Wi-Fi + BLE 5, 8 MB flash, 2 MB PSRAM
U4 | 1 | TMP117 | Texas Instruments | TMP117AIDRVR | TI TMP117AIDRVR high-accuracy digital temperature sensor, WSON-6 (DRV) | WSON-6-DRV0006B |  |  |  | TMP117 | Digital temperature sensor, I2C addr 0x48
U5 | 1 | LSM6DSOX | STMicroelectronics | LSM6DSOXTR | ST LSM6DSOXTR 6-axis IMU (3-axis accel + 3-axis gyro), LGA-14L | LGA-14L-2.5X3.0 |  |  |  | LSM6DSOX | 6-axis IMU, I2C addr 0x6A
U6 | 1 | AS5600 | ams-OSRAM | AS5600-ASOM | ams-OSRAM AS5600-ASOM 12-bit contactless magnetic rotary position sensor, SOIC-8 | SOIC-8-N |  |  |  | AS5600 | 12-bit magnetic angle sensor, I2C addr 0x36 (fixed)
U7 | 1 | AD8232 | Analog Devices | AD8232ACPZ-R7 | Analog Devices AD8232ACPZ-R7 single-lead heart-rate monitor front end | LFCSP-20-4X4-P050 |  |  |  | AD8232 | Single-lead ECG analog front end (Vs 2.0-3.5 V)
U8 | 1 | HX711 | Avia Semiconductor | HX711 | Avia Semiconductor HX711 24-bit ADC for bridge sensors, SOP-16L | SOP-16-N |  |  |  | HX711 | 24-bit bridge ADC for the load cell

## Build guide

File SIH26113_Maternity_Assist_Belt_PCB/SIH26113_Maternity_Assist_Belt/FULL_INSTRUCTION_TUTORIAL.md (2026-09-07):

<!--
  FULL_INSTRUCTION_TUTORIAL.md
  SIH26113 - Maternity Assist Belt - Prototype Carrier PCB
  The single complete walkthrough: from "I have never opened an EDA tool"
  to "the boards arrived and the ECG channel works".

  This document is hand-written, not generated. The generated documents it
  refers to are marked [generated] and are rebuilt by scripts/build_all.py.
-->

<div align="center">

# 📘 FULL INSTRUCTION TUTORIAL

### SIH26113 — Maternity Assist Belt · Prototype Carrier PCB

**Smart India Hackathon 2026 · Problem Statement SIH26113 · Team Rocket 🚀**

*Everything, A to Z. Every file, every script, every workflow, every number,
every thing that can go wrong — in the order you will actually need it.*

</div>

---

$$\Huge\textcolor{red}{\textsf{⛔ STOP — READ PART 1 FIRST ⛔}}$$

$$\large\textcolor{red}{\textsf{3 BLOCKING items. One of them is a fire risk.}}$$

$$\large\textcolor{orange}{\textsf{6 more must be settled before you spend money on PCBs.}}$$

> [!CAUTION]
> ### 🔴 This board has **no battery-protection circuit** and **no ECG isolation**.
>
> If you connect an **unprotected** lithium cell to `J1`, you have built a fire
> hazard. If you attach ECG electrodes to a person **while USB is plugged in**,
> you have galvanically connected that person to a mains-derived supply through
> 330 kΩ.
>
> Neither of those is a bug. Both are documented, deliberate boundaries of a
> prototype. But you have to know about them **before** you power anything.
>
> **→ Jump straight to [PART 1 — THE BLOCKERS](#part-1--the-blockers-read-this-before-anything-else).**

> [!WARNING]
> ### 🟠 This is **not a medical device** and must never be presented as one.
>
> No IEC 60601-1 and no IEC 60601-2-47 compliance work has been done, and none
> is claimed. This is an engineering prototype for bench evaluation by informed
> participants. It measures a biopotential; it does not diagnose anything.

---

## 🧭 How to read this document

It is long on purpose. You are **not** meant to read it front to back in one
sitting. Pick your route:

| If you are… | Read, in this order | Roughly |
|---|---|---|
| **Judging / evaluating the project** | Part 1 → Part 2 → Part 3 → Part 5 → Part 26 | 30 min |
| **A teammate picking this up cold** | Part 1 → Part 2 → Part 4 → Part 5 → Part 6 → Part 16 | 2 hours |
| **About to open it in Fusion** | Part 1 → Part 3 → Part 13 → Part 19 (Workflow D) | 1 hour, then a day of work |
| **About to order boards** | Part 1 → Part 20 (Workflow E) → Part 29 checklists | 1 hour |
| **About to solder** | Part 21 (Workflow F) → Part 22 (Workflow G) | read fully before you start |
| **Writing the firmware** | Part 9 → Part 23 (Workflow H) → Part 11 | 2 hours |
| **Changing the design** | Part 6 → Part 7 → Part 18 (Workflow C) | 2 hours |
| **Debugging a board that does not work** | Part 24 (Troubleshooting) | as needed |
| **Here to learn how it was engineered** | Part 31 → Part 6 → Part 14 → Part 15 | 1 hour |

### Conventions used everywhere below

| Marker | Meaning |
|---|---|
| 🔴 **BLOCKING** | Can destroy hardware or hurt a person. Resolve before power. |
| 🟠 **HIGH** | Changes a component value or a footprint. Resolve before ordering PCBs. |
| 🟡 **MEDIUM** | Affects performance. Verify before or during bring-up. |
| ⚪ **LOW** | Cosmetic or convenience. |
| ✅ | Verified against primary documentation, or checked by a script that ran. |
| ❌ **NOT EXECUTED** | A tool that would normally check this was **not available**. Never presented as passing. |
| `J1`, `R45`, `U7` | A reference designator — a specific physical part on the board. |
| `VBAT`, `ECG_OUT` | A net name — a specific electrical connection. |
| `IO35` | An ESP32-S3 module pin. |
| **§** | A section in one of the other documents in `documentation/`. |

### The one rule this whole project follows

> **Nothing is claimed as passing a tool that was never run.**
>
> There is no EDA software installed in the environment where these files were
> produced. So the library, schematic and board were generated directly as
> EAGLE 9 XML from a Python model, and *independent* ERC and DRC checkers were
> written and run against the emitted files. Those pass. **Autodesk Fusion's
> own ERC and DRC have not been run**, and every document says so in those
> words. Running them is your job, and it is Part 19 of this tutorial.

---

## 📑 Table of contents

**Front matter**
- [PART 1 — THE BLOCKERS](#part-1--the-blockers-read-this-before-anything-else) 🔴🟠 ← *start here*
- [PART 2 — What this project actually is](#part-2--what-this-project-actually-is)
- [PART 3 — Exactly how complete this is](#part-3--exactly-how-complete-this-is)

**Getting set up**
- [PART 4 — Absolute-beginner setup](#part-4--absolute-beginner-setup)
- [PART 5 — Every single file, explained](#part-5--every-single-file-explained)

**Understanding the machinery**
- [PART 6 — The generated-from-source model](#part-6--the-generated-from-source-model)
- [PART 7 — Every script, explained](#part-7--every-script-explained)

**Understanding the electronics**
- [PART 8 — The circuit, sheet by sheet](#part-8--the-circuit-sheet-by-sheet)
- [PART 9 — GPIO allocation and its two hard constraints](#part-9--gpio-allocation-and-its-two-hard-constraints)
- [PART 10 — Power budget, in full](#part-10--power-budget-in-full)
- [PART 11 — The ECG front end, in depth](#part-11--the-ecg-front-end-in-depth)
- [PART 12 — Grounding and the stack-up](#part-12--grounding-and-the-stack-up)

**Understanding the board**
- [PART 13 — The physical board](#part-13--the-physical-board)
- [PART 14 — How the router works](#part-14--how-the-router-works)
- [PART 15 — Verification: what was checked and how](#part-15--verification-what-was-checked-and-how)

**Workflows — the actual doing**
- [PART 16 — Workflow A: understand it without installing anything](#part-16--workflow-a-understand-it-without-installing-anything)
- [PART 17 — Workflow B: regenerate the entire project](#part-17--workflow-b-regenerate-the-entire-project)
- [PART 18 — Workflow C: change the design](#part-18--workflow-c-change-the-design)
- [PART 19 — Workflow D: open it in Autodesk Fusion, all 20 steps](#part-19--workflow-d-open-it-in-autodesk-fusion-all-20-steps)
- [PART 20 — Workflow E: order the PCB](#part-20--workflow-e-order-the-pcb)
- [PART 21 — Workflow F: assemble the board](#part-21--workflow-f-assemble-the-board)
- [PART 22 — Workflow G: bring-up, in six stages](#part-22--workflow-g-bring-up-in-six-stages)
- [PART 23 — Workflow H: firmware](#part-23--workflow-h-firmware)

**Reference**
- [PART 24 — Troubleshooting encyclopedia](#part-24--troubleshooting-encyclopedia)
- [PART 25 — The seven architecture changes](#part-25--the-seven-architecture-changes)
- [PART 26 — Known limitations, honestly](#part-26--known-limitations-honestly)
- [PART 27 — Glossary](#part-27--glossary)
- [PART 28 — FAQ](#part-28--faq)
- [PART 29 — Printable checklists](#part-29--printable-checklists)
- [PART 30 — Appendices](#part-30--appendices)
- [PART 31 — Engineering log: what was built, what broke, and what it taught](#part-31--engineering-log-what-was-built-what-broke-and-what-it-taught) ← *the routing story and the 11 defects*

---

# PART 1 — THE BLOCKERS (read this before anything else)

$$\Huge\textcolor{red}{\textsf{🔴 BLOCKING — 3 items}}$$

$$\normalsize\textcolor{red}{\textsf{These can destroy hardware or hurt a person. Resolve BEFORE applying power.}}$$

The authoritative, always-current version of this list is
[`documentation/REQUIRES_CONFIRMATION.md`](documentation/REQUIRES_CONFIRMATION.md).
This part reproduces it with more explanation and adds the *how to clear it*
that the source document leaves implicit.

Every item below is a checkbox. **Tick them in the source document as you go**,
so the next person knows where you got to.

---

<table>
<tr><td bgcolor="#b71c1c">

## 🔴 B1 — The Li-Po cell at `J1` **must** have integrated protection

</td></tr>
</table>

> [!CAUTION]
> **There is no battery protection circuit on this board.**
> An unprotected Li-Po cell connected to `J1` is a fire risk.

### What happened and why

The architecture diagram that this project started from said:

> "JST → TP4056 **protected** module"

That word *protected* is doing a lot of work. A commercial **TP4056 module** —
the little red PCB you buy for a dollar — carries **two** circuits:

| On the module | Function |
|---|---|
| **TP4056** | the linear charge controller |
| **DW01A + FS8205A** | the *protection* circuit: over-charge, over-discharge, over-current cut-off |

This design uses the **TP4056 as a bare IC** (`U1`, SOIC-8), because a
board-level charger is the right thing for a real product and because dropping
a purchased module onto a carrier board is not a PCB design. That means the
charge controller is present and **the protection circuit is not**.

Bare DW01A and FS8205A were deliberately **not** added, because their pinouts
could not be verified against primary manufacturer documentation from the
environment these files were produced in. Guessing at the pinout of a lithium
protection circuit — the one circuit whose failure mode is a fire — is not an
acceptable risk. Marking it as an open item is.

### What to confirm

**The cell or pack fitted to `J1` has an integrated protection circuit module
(PCM)** providing all three of:

- over-charge cut-off (typically ~4.25–4.35 V)
- over-discharge cut-off (typically ~2.4–3.0 V)
- over-current / short-circuit cut-off

### How to clear it — step by step

1. **Buy a protected 1S Li-Po pack.** Search terms: *"1S 3.7 V Li-Po with PCM"*,
   *"protected lithium polymer JST-PH"*. Almost every cell sold for
   prototyping already has one — you have to go out of your way to buy a bare
   cell. Bare cells are usually sold as "cell only", "for pack assembly", or
   with bare nickel tabs instead of wires.
2. **Physically verify the PCM is there.** Peel back the yellow Kapton tape at
   the end where the wires exit. You are looking for a **small PCB, roughly
   4 × 12 mm, with a black 6-pin or 8-pin chip and a second larger chip.**
   Two wires leaving a bare foil tab with no PCB = **unprotected, do not use**.
3. **Meter the JST pigtail before the first connection.**

   > 🔴 **JST PH pigtails are NOT consistently wired between suppliers.**
   > Some vendors put + on pin 1, some on pin 2. Reversing this puts the cell
   > backwards across the charger and the whole 3V3 rail.

   - `J1` **pin 1 = `VBAT` (+)**
   - `J1` **pin 2 = `GND` (−)**
   - Pin 1 is the **square pad** on the board silkscreen. Every through-hole
     connector on this board marks pin 1 with a square pad — that is
     manufacturing check item 16.
   - Set a multimeter to DC volts, put the black probe on the pigtail contact
     that will land in pin 2, red on pin 1. **You must read a positive number
     between 3.0 and 4.2 V.** If it reads negative, the pigtail is reversed:
     re-crimp it, or cut and swap the wires. Do not "just remember".
4. Tick B1 in `documentation/REQUIRES_CONFIRMATION.md`.

### If you would rather have protection on the board

That is a legitimate choice and it is a real design change, not a tweak. It
means adding DW01A + FS8205A (or a modern integrated equivalent) to the
library with a **verified** pinout, wiring them between the cell and `VBAT`,
re-running the whole generate chain, and re-routing. Budget a day. See
[Part 18 — Workflow C](#part-18--workflow-c-change-the-design) for how to add
a part to the model.

### What it costs you if you get it wrong

A 1S Li-Po driven past 4.3 V, or shorted, vents and then burns. It is not a
"the board stops working" failure mode. This is the single most consequential
line in the entire project.

---

<table>
<tr><td bgcolor="#b71c1c">

## 🔴 B2 — ECG electrical safety — this is not a medical device

</td></tr>
</table>

> [!CAUTION]
> The ECG channel connects to a **human being**. There is **no galvanic
> isolation** anywhere in that path.

### What the board **does** provide

| Protection | Value | Source of the rule |
|---|---|---|
| Series resistance, each electrode (LA, RA) | **330 kΩ** (`R18`, `R19`) | AD8232 datasheet's own patient-protection guidance |
| Series resistance, driven RLD electrode | **330 kΩ** (`R20`) | AD8232 datasheet: > 330 kΩ at 3.0 V |
| Resulting worst-case fault current | **< 10 µA at 3.3 V** | 3.3 V / 330 kΩ = 10 µA |
| Supply when USB is unplugged | battery only, floating | — |

10 µA is a *very* small number. For scale, the threshold of human perception
for DC current through skin is on the order of a milliamp — a hundred times
larger.

### What the board does **NOT** provide

| Missing | Consequence |
|---|---|
| **Galvanic isolation** between subject and circuit | there is a DC path (through 330 kΩ) from the electrode to the board's ground |
| **Defibrillation protection** | no gas-discharge tubes, no neon lamps, no BAV199-class clamps — which is the AD8232 datasheet's own recommendation *for that case*. If someone is defibrillated while wearing this, the front end is destroyed and the energy path is undefined. |
| **Mains isolation while USB is connected** | 🔴 **this is the one that matters in practice** |

### 🔴 The USB problem, stated plainly

`J2` is the 5 V / USB header. If you plug it into a **mains-powered** USB
supply — a phone charger, a laptop that is itself plugged in, a desktop PC —
then the subject wearing the electrodes is **galvanically connected to that
supply's secondary through 330 kΩ**.

A good USB supply's secondary is isolated from mains and referenced to earth
through its own Y-capacitor. A cheap or failed one may not be. You cannot tell
by looking.

### How to clear it — the protocol

You clear B2 with a **written rule that everyone involved follows**, not with a
purchase.

1. > 🔴 **Electrodes are only ever attached while the board is running on
   > battery, with the USB cable physically unplugged from `J2`.**
   >
   > Not "USB plugged in but the host powered off". Not "USB plugged into a
   > power bank". **Unplugged.** A power bank is defensible but the rule is
   > only useful if it is absolute and unambiguous.
2. **Bench evaluation only, with informed adult participants** who have been
   told what the device is, what it is not, and that it has no medical
   approval.
3. **Never on a person who is pregnant** as part of a demo, despite that being
   the project's eventual target population, until the design has been through
   actual safety engineering. The target application does not license the
   prototype.
4. **Nobody presents it as a medical device** — not in a pitch, not in a
   README, not in a demo video, not verbally. No IEC 60601-1 or IEC 60601-2-47
   compliance work has been done and none is claimed.
5. Write those four lines on a card and tape it inside the enclosure lid.
6. Tick B2 in `documentation/REQUIRES_CONFIRMATION.md`.

### If you need ECG **while** mains-powered

That is a different board. It needs an isolated supply (a medical-grade
isolated DC-DC), an isolated data link (digital isolator or optical), and
patient-connection design to a standard. That is a redesign, not a
modification. Do not try to bolt it on.

---

<table>
<tr><td bgcolor="#b71c1c">

## 🔴 B3 — Vibration motor voltage rating vs. `R45`

</td></tr>
</table>

> [!CAUTION]
> The motor sits directly on `VBAT`, which is **3.0 – 4.2 V**. Most coin ERM
> motors are rated **3.0 V**. Running a 3.0 V motor at 4.2 V will shorten its
> life dramatically and may destroy it.

### The circuit

```
VBAT ──► R45 (0 Ω, 0805) ──► J16 pin 1 ──[ MOTOR ]── J16 pin 2 ──► Q1 drain
                                                                     │
                                              D7 flyback across      │
                                              the motor              │
                       IO47 ──► R43 (100 Ω) ──► Q1 gate              │
                                              R44 (100 kΩ) gate pull-down
                                                                  Q1 source ──► GND
```

- `Q1` = **AO3400A**, N-channel logic-level MOSFET, SOT-23-3, rated **5.7 A**
- `D7` = **1N5819HW** Schottky flyback, anode on the switched drain, cathode
  on the supply — checked by ERC rule R10
- `R44` = 100 kΩ gate pull-down so the FET is **off** if `IO47` floats at boot
- `R45` = **0 Ω 0805**, deliberately present so the motor rail can be adapted
  **without cutting tracks**

`R45` exists for exactly this reason. It is a designed-in escape hatch.

### What to confirm

The motor's **rated voltage** and **rated current**, and its **stall current**.

### How to clear it — the decision table

| Motor rated voltage | Action on `R45` |
|---|---|
| **≥ 4.2 V** | leave `R45` at **0 Ω**. Done. |
| **3.0 V** (most coin ERM types) | **populate `R45`** with a ballast resistor, calculated below |

### Worked example — a 3.0 V / 100 mA coin ERM

**Step 1 — the resistance.**

$$R_{45} = \frac{V_{BAT,max} - V_{motor}}{I_{motor}} = \frac{4.2 - 3.0}{0.1} = 12\ \Omega$$

**Step 2 — the power, which is the part people forget.**

$$P_{R45} = I^2 R = 0.1^2 \times 12 = 0.12\ \text{W} = 120\ \text{mW}$$

An **0805 chip resistor is rated 125 mW**. 120 mW in a 125 mW part is
**marginal** — 96 % of rating, with no derating for ambient temperature inside
a sealed enclosure worn against a body.

**Step 3 — fix the power problem.** Two options, both fine:

| Option | How |
|---|---|
| **Two 24 Ω in parallel** | 24 ‖ 24 = 12 Ω, 60 mW each, both well inside rating. Needs a second pad — you can tack the second resistor on top of the first, or add a footprint (Workflow C). |
| **One 1206 resistor** | 1206 is rated 250 mW. 120 mW is comfortable. An 0805 part fits on a 1206 land but **not** the other way round — so this needs a footprint change in `lib_defs.py` and a re-run. |

**Recommendation:** if you are hand-building one prototype, stack two 24 Ω
0805s. If you are ordering a second batch of boards, change `R45` to 1206 in
the model properly.

**Step 4 — note that the drop only applies at full charge.** At 3.7 V nominal
the motor sees 3.7 − (0.1 × 12) = 2.5 V and runs slightly weak; at 3.0 V it
barely turns. A resistive ballast trades top-end protection for bottom-end
performance. If that bothers you, the correct answer is PWM from `IO47` with a
duty cycle scheduled against the measured `VBAT_SENSE` — the hardware already
supports it, it is purely firmware, and it is described in
[Part 23](#part-23--workflow-h-firmware).

### Also confirm stall current

Coin-ERM **stall current can be 3–4× the running current**. For a 100 mA motor
that is 300–400 mA. Check it against:

| Element | Rating | Margin at 400 mA |
|---|---|---|
| `Q1` AO3400A | **5.7 A** continuous | 14× |
| Motor track, 0.50 mm, 1 oz copper, 10 °C rise | **≈ 1.45 A** (IPC-2221) | 3.6× |
| `R45` if fitted at 12 Ω | 0.4² × 12 = **1.9 W** ← 🔴 | **fails instantly** |

That last row matters: **a stalled motor destroys the ballast resistor**, and
possibly opens it (which is a safe failure) or chars the board (which is not).
If your motor can stall in normal use — a belt-mounted motor pressed against
fabric can — then either drive it in short pulses only, or use PWM without a
ballast, or fit a resistor with real margin.

Tick B3 in `documentation/REQUIRES_CONFIRMATION.md`.

---

$$\Huge\textcolor{orange}{\textsf{🟠 HIGH — 6 items}}$$

$$\normalsize\textcolor{orange}{\textsf{These change a component value or a footprint. Resolve BEFORE ordering PCBs.}}$$

---

<table>
<tr><td bgcolor="#e65100">

## 🟠 H1 — MAX17048 fuel gauge is **not on the board**

</td></tr>
</table>

> [!WARNING]
> The architecture diagram called for a MAX17048 battery fuel gauge. It is not
> placed, because its datasheet could not be retrieved.

**Why.** `analog.com` and every distributor mirror that was tried were either
unreachable or bot-blocked from the network these files were produced on. That
means **neither the MAX17048's pinout nor its land pattern could be verified**.
Drawing an unverified footprint for a part and shipping it in a library is how
you get a board that cannot be assembled. So it was left out and the omission
documented.

Both of its packages are also awkward for a hackathon build: the 8-bump
**0.9 × 1.7 mm WLP is not hand-assemblable at all**, and the TDFN-8 is a
0.5 mm-pitch leadless part.

**Provided instead:**

| Part | What it gives you |
|---|---|
| `J4` — 5-way header (`VBAT`, `GND`, `3V3`, `SDA`, `SCL`) | plug in an off-the-shelf MAX17048 breakout. SparkFun and Adafruit both make one. It sits at **0x36 on the sensor bus**, which is already reserved for it. |
| `R5` / `R6` / `C6` — 470 kΩ / 470 kΩ divider + filter to `IO9` | battery voltage by ADC, **always available**, no gauge required. 4.2 V cell → 2.10 V at the pin. |

**How to clear it.** Decide whether you want the gauge at all.

- **You probably do not need it.** A divider tells you cell voltage. A fuel
  gauge tells you *state of charge*, which is a much better number, but for a
  prototype the voltage is enough — and the firmware needs the voltage anyway
  for the low-battery cut-off (see Part 10).
- **If you want it:** buy a breakout, plug it into `J4`. Zero board changes.
- **If you want it on-board:** obtain the datasheet, verify the TDFN-8 land
  pattern against Analog Devices' own recommended land pattern drawing, add it
  to `lib_defs.py`, and re-run the chain.

---

<table>
<tr><td bgcolor="#e65100">

## 🟠 H2 — Abdominal stretch sensor: `R37` is a **placeholder**

</td></tr>
</table>

> [!WARNING]
> `R37` = 10 kΩ is **a placeholder, not a design value.** It was put there so
> the schematic and board are complete; it is almost certainly wrong for
> whatever sensor you buy.

### The circuit

`J13` brings in a two-terminal resistive stretch sensor. `R37` forms the lower
leg of a divider from `3V3`, `C33` (10 nF) filters it, and the wiper goes to
`IO8` = `ADC1_CH7`.

### Why a placeholder is wrong and what the right value is

A resistive divider has maximum sensitivity when its output sits near
mid-rail. For a sensor that swings between `R_min` (relaxed) and `R_max`
(stretched), the value that centres the output across the whole span is the
**geometric mean**:

$$R_{37} = \sqrt{R_{min} \times R_{max}}$$

This is the same method used for the four FSR dividers, whose 10 kΩ value
**is** derived — see `DESIGN_ASSUMPTIONS.md` §7.1. `R37` just has no sensor to
derive from yet.

### How to clear it

1. Choose the sensor and get its part number.
2. Measure or look up its resistance at **minimum** and **maximum** useful
   extension. Measure it if you can — published figures for conductive-rubber
   stretch sensors are wide.
3. Compute √(R_min × R_max).
4. **Check both extremes do not clip.** Compute the divider output at R_min and
   at R_max and confirm both land between roughly 0.15 V and 3.15 V. The
   ESP32-S3 ADC is not usable right at the rails.
5. Set `R37` in `scripts/design.py` and re-run, **or** just fit the right
   resistor to the built board.

**Good news:** `R37` is a single 0805. This is a **reworkable change, not a
re-spin.** You can order the boards with H2 unresolved.

---

<table>
<tr><td bgcolor="#e65100">

## 🟠 H3 — Load cell: bridge resistance and sensitivity unknown

</td></tr>
</table>

> [!WARNING]
> Two of the load cell's parameters affect the design and neither is known yet.

### The circuit

The board excites the bridge from `3V3` via `J8` (a JST-PH-4) and reads it on
**HX711 channel A at gain 128** — that is ±20 mV full scale, **ratiometric to
AVDD**, which is why exciting from the same 3V3 rail is correct rather than
lazy (see `DESIGN_ASSUMPTIONS.md` §7.2).

| `J8` pin | Signal |
|---|---|
| 1 | **E+** — excitation positive |
| 2 | **E−** — excitation negative |
| 3 | **A+** — signal positive |
| 4 | **A−** — signal negative |

### What to confirm

**1. Bridge resistance** — this affects the power budget.

| Bridge | Excitation current at 3.3 V |
|---|---|
| 350 Ω | **9.4 mA** ← already budgeted as the worst case |
| 1 kΩ | 3.3 mA |

**2. Sensitivity in mV/V** — this decides whether gain 128 is right.

| Cell | Full-scale output at 3.3 V excitation | Verdict at gain 128 (±20 mV) |
|---|---|---|
| 1 mV/V | 3.3 mV | comfortable |
| 2 mV/V | 6.6 mV | fine |
| 6 mV/V | 19.8 mV | **at the limit** |
| > 6 mV/V | > 20 mV | **clips — drop to gain 64** |

Gain is selected by the HX711's clock-pulse count in firmware, so this is a
**software** change, not a hardware one. But you need to know the number.

**3. Wire colours — 🟠 do NOT assume.**

> The red/black/white/green convention is **not universal.** Chinese-sourced
> load cells frequently differ, and getting E and A swapped means the HX711
> reads the excitation rail instead of the bridge output.

**How to identify the pairs with a multimeter, reliably:**

1. Measure resistance between all six wire pairs.
2. The **two highest** readings are the *bridge input* pair (E+/E−) and the
   *bridge output* pair (A+/A−) — in a balanced bridge these are close.
3. The **four lower, roughly equal** readings are the individual arms.
4. Practically: the pair with the **highest** resistance is **E+/E−**. The
   remaining pair of the two "high" readings is **A+/A−**.
5. E+/E− polarity does not matter electrically for excitation, but A+/A−
   polarity determines whether the reading goes up or down under load — and
   that is trivially fixable in firmware. Get E and A right; do not worry
   about which way round A+ and A− are.

---

<table>
<tr><td bgcolor="#e65100">

## 🟠 H4 — Tactile switch footprint (`SW2`, `SW3`, `SW4`)

</td></tr>
</table>

> [!WARNING]
> A transposed switch **will not fit the board**. Check the drawing before you
> order PCBs.

The library footprint `TACT-6X6-THT` is the de-facto standard 6 × 6 mm
through-hole tactile geometry:

| Property | Value |
|---|---|
| Lead grid | **6.5 × 4.5 mm** |
| Drill | 1.0 mm |
| Internal bonding | leads **1–2** common, leads **3–4** common (TL1105 / B3F-10xx family) |

That internal bonding is why the library symbol uses EAGLE's **multi-pad
connect** (`pad="1 2"`): two physical pads, one electrical node. It is correct
and it is also why the schematic shows a two-terminal switch with four pads.

**What goes wrong.** Some 6 × 6 mm switches use **4.5 × 6.5 mm** — the same
grid rotated 90° — and some are 2-lead only. Both are sold as "6×6 tactile".

**How to clear it.** Open your chosen vendor part's mechanical drawing. Find
the lead pitch dimensions. Confirm **6.5 mm in the direction the footprint
expects**. If it is transposed, either:

- buy a different switch (easiest), or
- rotate the placement 90° in `design.py` (`rot` field on the part), or
- edit the footprint in `lib_defs.py` and re-run.

Used for `SW2` = RESET, `SW3` = BOOT, `SW4` = SOS.

---

<table>
<tr><td bgcolor="#e65100">

## 🟠 H5 — ESP32-S3 module variant: `-N8R2` is **not optional**

</td></tr>
</table>

$$\large\textcolor{orange}{\textsf{Order ESP32-S3-WROOM-1-N8R2. Do NOT substitute N8R8 or N16R8.}}$$

> [!WARNING]
> This is the single most likely purchasing mistake on the whole project,
> because the variants look identical and are usually the same price.

### Why

*ESP32-S3-WROOM-1 & WROOM-1U Datasheet v1.8*, **Table 3-1, note b**: on
Octal-SPI-PSRAM modules (the `R8` and `R16V` variants), **IO35, IO36 and IO37
are connected to the PSRAM and are unavailable**.

This design uses **all three of them**:

| Pin | Net | Function |
|---|---|---|
| `IO35` | `ECG_LOD_P` | ECG leads-off detect, + input |
| `IO36` | `ECG_LOD_N` | ECG leads-off detect, − input |
| `IO37` | `ECG_SDN` | ECG front-end shutdown control |

Fitting an octal-PSRAM part **shorts three ECG control signals into the PSRAM
bus.** The module will probably still boot; the ECG channel will not work and
the PSRAM will be corrupted.

### And a second, quieter reason

`-N8R2` keeps **VDD_SPI at 3.3 V**. That makes `IO47` and `IO48` — the
**vibration motor and buzzer gate drives** — 3.3 V logic. On `R16V` parts
VDD_SPI is 1.8 V, and 1.8 V is not reliably enough to fully enhance an AO3400A
gate. You would get a hot, partially-on FET.

### How to clear it

1. When ordering, read the **full** part number on the listing, not the title.
   The suffix is printed on the module's own shield.
2. `N8` = 8 MB flash. `R2` = **2 MB quad-SPI PSRAM** ← this is what you want.
3. `R8` / `R16V` = 8 MB / 16 MB **octal**-SPI PSRAM ← do not buy.
4. If a supplier ships the wrong one, **do not fit it "just to test"**. It will
   read as a hardware fault in the ECG channel and cost you a day of debugging.

---

<table>
<tr><td bgcolor="#e65100">

## 🟠 H6 — Fabricator must support 5 mil / 0.127 mm trace and gap

</td></tr>
</table>

> [!WARNING]
> **Measured minimum copper clearance anywhere on the board: 0.130 mm.**
> A 6 mil (0.152 mm) process — which is frequently the *default* — cannot make
> this board.

### The numbers to quote the fab

| Parameter | Value |
|---|---|
| Copper layers | **4** |
| Minimum clearance, **measured** | **0.130 mm** |
| Clearance rule, general | 0.15 mm |
| Clearance rule, inside the 4 fine-pitch fan-outs | **0.127 mm (5 mil)** |
| Minimum track | **0.15 mm** (fine-pitch escapes only) |
| Track elsewhere | 0.20 mm signal, 0.50 mm power and motor |
| Minimum drill | **0.30 mm** |
| Board | 100 × 70 mm, 1.6 mm FR-4, 1 oz outer copper |
| Stack-up | `(1*2*15*16)` — layers 2 and 15 are **planes** |

### Why the board needs it — this is physics, not sloppiness

A **0.5 mm-pitch QFN cannot be escaped at 0.15 mm track / 0.15 mm gap.** Do
the arithmetic: 0.5 mm pitch with a 0.25 mm pad leaves 0.25 mm of gap between
adjacent pads. Putting a 0.15 mm track down the middle of that leaves
(0.25 − 0.15) / 2 = **0.05 mm** each side. It does not fit. Narrowing the
escape track to 0.15 mm and allowing 0.127 mm clearance **inside the fan-out
region only** is what makes it fit.

That exception applies **only inside four named rectangles** — around the
AD8232, LSM6DSOX, TMP117 and HX711. `scripts/validate_drc.py` enforces it as a
region, not globally, and any pair between 0.10 and 0.15 mm inside one of them
is printed as a NOTE rather than passed silently. Everywhere else the board
holds **0.154 mm or better** track-to-track.

### How to clear it

1. Go to your fab's ordering page (JLCPCB, PCBWay, Aisler, Eurocircuits…).
2. Set layers = 4.
3. Find the **"Minimum trace/spacing"** or **"Track/Gap"** option. It will
   probably default to **6/6 mil**. Change it to **5/5 mil**.
4. Confirm the price. On JLCPCB and PCBWay, 5 mil on 4 layers is a standard
   option; it may add a small charge or a longer lead time.
5. If a fab will not quote 5 mil, **do not just order it anyway.** They will
   either reject the file or, worse, build it with shorts. Instead see the
   fallback below.

### 🟠 Fallback if your fab is 6 mil only

The design can be widened to 6 mil, but it is real work and it costs you:

- change `FINE_PITCH_CLEARANCE` in `scripts/design.py` from `0.127` to `0.152`
- re-run `python scripts/generate_board.py` (it will re-route from scratch)
- **expect the unrouted-net count to rise above the current 4.** The fan-outs
  are the tightest spots on the board; giving them more clearance means fewer
  escapes fit.
- then finish more nets by hand in Fusion.

It is a viable path, not a dead end. See
[Part 18 — Workflow C](#part-18--workflow-c-change-the-design).

---

$$\Large\textcolor{gold}{\textsf{🟡 MEDIUM — 7 items}}$$

*Verify before or during bring-up. These affect performance, not safety.*
Full text in `documentation/REQUIRES_CONFIRMATION.md`.

| # | Item | One-line summary | How to clear |
|---|---|---|---|
| **M1** | ESP32-S3 EPAD land position | All 40 signal pads are ✅ verified against Espressif Fig. 11-1 including the pin-1 datum (7.49 mm below the antenna edge), so **the module will solder correctly**. The thermal pad is emitted as one conservative 3.4 mm land, deliberately **smaller** than the module's exposed metal, plus 9 plated vias. Espressif sub-divides it into a 3 × 3 array on a 3.7 mm span. | Open the footprint in Fusion against Espressif's downloadable land-pattern file (linked from datasheet §11.1). Worst case if offset ~1 mm: slightly worse thermal contact. **It cannot cause a short.** |
| ✅ **M2** | USB differential-pair impedance | **RESOLVED — calculated, see `documentation/USB_PAIR_ANALYSIS.md`.** The pair is **≈ 165 Ω, not 90 Ω (83 % high)**: it was routed as two ordinary signals with a 0.806 mm closest gap (2.24 × h), so the coupling term collapses to 5.6 % and you have two independent 87 Ω microstrips. | **No action needed.** ESP32-S3 USB is Full Speed only. 255 ps one-way over 44 mm vs a 115 mm conservative critical length at the fastest permitted 4 ns edge → **electrically short by 2.6×**, so it is lumped and the mismatch causes no reflections. Skew 5 ps. For 90 Ω you would need **0.40 mm wide / 0.16 mm gap on one layer**. |
| **M3** | Buzzer type | Drives `J17` low-side from `3V3` through `Q2`, `D8` flyback. **Firmware differs by type.** | **Active magnetic** (own oscillator) → drive `IO48` on/off; `D8` essential. **Passive piezo** → drive `IO48` with LEDC PWM at its resonance, typically 2–4 kHz; `D8` harmless. Confirm current draw; 30 mA budgeted. |
| **M4** | Piezo film capacitance vs `R38` | `R38` = 10 MΩ sets the corner at 1/(2π·10M·C_film). At an assumed ~1.5 nF that is ≈ **10 Hz**, suiting fetal movement (~1–10 Hz). | Measure the film's capacitance. Larger (10 nF+) → corner drops to ~1.6 Hz, which is fine or better. Much smaller → corner rises and low-frequency movement is attenuated; reduce `R38`. **`C34` must be ≥ 50 V rated** (specified `100n/50V`) — a piezo film's open-circuit transient reaches tens of volts. |
| ✅ **M5** | AS5600 3.3 V-mode strapping | **RESOLVED — the design is correct.** *AS5600 Datasheet [v1-06] 2018-Jun-20*, page 9, states verbatim: *"In 3.3V operation, the VDD5V and VDD3V3 pins must be tied together. VDD is the voltage level present at the VDD5V pin."* The board ties both to `3V3`. Per-pin decoupling matches page 3 (100 nF on `VDD5V`, 1 µF on `VDD3V3`). | **No action needed.** |
| **M6** | Magnet for the AS5600 | The AS5600 measures a diametrically-magnetised on-axis magnet. **No magnet mount exists on this PCB** — it is a mechanical-design item. | Specify magnet type (diametric NdFeB, typically 6 × 2.5 mm), air gap 0.5–3 mm, centred over the IC within ~0.25 mm. If it must live at the belt's rail joint instead, move it to a flying lead on `J6` — the angle bus is already brought out there. |
| **M7** | TMP117 measures **pod** temperature, not skin temperature | `U4` is on the main board because that is where the architecture diagram puts it. Inside an electronics pod it measures the pod's internal temperature, influenced by the LDO, the charger and the ESP32. | Decide whether skin temperature is actually required. If yes, **relocate the TMP117 to a short flex tail** with the sensor against the skin — the sensor I²C bus is already on `J4`. **This is a real measurement problem, not a layout nicety.** |

---

$$\Large\textcolor{gray}{\textsf{⚪ LOW — 4 items}}$$

| # | Item | Summary |
|---|---|---|
| **L1** | Mounting holes are not at four corners | `H1` (3, 3), `H2` (97, 3), `H4` (97, 67) are corners. **`H3` is at (2.6, 42)** — mid-left edge — because the top-left corner is inside the module's antenna keep-out and a plated hole there would detune the antenna. Confirm the enclosure accepts that pattern. |
| **L2** | `J3` on/off switch polarity is **inverted** | `R4` pulls the LDO's `EN` up to `VBAT`, so **the default state is ON**, and **closing a switch across `J3` turns the board OFF.** Silkscreened `OFF SW`. Deliberate — it avoids inventing an unverified slide-switch footprint — but it is the opposite of what most people expect. **Tell whoever wires the enclosure.** |
| **L3** | Silkscreen legibility at 1.0 mm | Reference designators use EAGLE's vector font at 0.8–1.1 mm. Most fabs hold 0.8 mm with a 0.15 mm stroke; some do not. Check your fab's minimum, increase the text sizes in `scripts/lib_defs.py` if needed. |
| **L4** | Supplier part numbers absent from the BOM | Deliberate. Distributor stock could not be checked, and a fabricated SKU is worse than a blank field. **Manufacturer** part numbers come from datasheet ordering guides and are correct. Fill in Supplier / Supplier PN / Lifecycle from your own distributor — particularly for the AD8232 (occasionally allocated) and the LSM6DSOX. |

---

## 🔵 And one requirement that is not in the blocker list at all

> [!IMPORTANT]
> ### Firmware **must** implement a low-battery cut-off at 3.5 V.
>
> This is not optional and it is not a nicety. It is a hardware limitation that
> only firmware can cover.

The AP2112K-3.3 LDO has **250 mV typical dropout at 600 mA**. So as the cell
discharges:

| `VBAT` | 3V3 rail output | ESP32-S3 (min 3.0 V) |
|---|---|---|
| 4.2 V (full) | 3.30 V | fine |
| 3.7 V (nominal) | 3.30 V | fine |
| 3.55 V | 3.30 V | at the edge of regulation |
| 3.30 V | ≈ 3.05 V | 🟠 **marginal** |
| 3.10 V | ≈ 2.85 V | 🔴 **below minimum — brown-out** |

**Implement:** read `VBAT_SENSE` on `IO9`. The divider is 470 k / 470 k, so
**3.5 V at the cell reads 1.75 V at the pin.** Below that, stop sampling,
notify the app, and enter deep sleep.

**Why it matters:** without this the board browns out unpredictably at the
bottom of the discharge curve. Unpredictable behaviour in a device with an
**SOS button** is worse than a clean shutdown. Code in
[Part 23](#part-23--workflow-h-firmware).

---

## ✅ The one-page blocker summary

Print this. Tick it.

| | Item | Blocks | Cleared by | Time |
|---|---|---|---|---|
| 🔴 | **B1** Protected cell + JST polarity | **powering the board** | buying a protected pack; one meter check | 10 min |
| 🔴 | **B2** ECG safety protocol | **attaching electrodes** | a written rule everyone follows | 10 min |
| 🔴 | **B3** Motor rating vs `R45` | **connecting the motor** | choosing a motor, then arithmetic | 30 min |
| 🟠 | **H5** Module must be `-N8R2` | **ordering parts** | reading the full part number | 2 min |
| 🟠 | **H6** Fab must quote 5 mil | **ordering PCBs** | one dropdown at the fab | 5 min |
| 🟠 | **H4** Switch pin grid 6.5 × 4.5 mm | **ordering PCBs** | reading a mechanical drawing | 10 min |
| 🟠 | **H2** `R37` stretch divider | *nothing* — reworkable | choosing the sensor | 20 min |
| 🟠 | **H3** Load cell bridge + mV/V | *nothing* — firmware gain | metering the cell | 20 min |
| 🟠 | **H1** MAX17048 decision | *nothing* | decide: breakout, divider only, or add it | 5 min |
| 🔵 | **Low-battery cut-off at 3.5 V** | **reliable operation** | ~15 lines of firmware | 30 min |

**Realistically:** B1, B2, H5, H6, H1 are decisions and purchases you can
settle today. B3, H2, H3, H4 need you to pick parts. Nothing here requires
re-designing the board.

---

# PART 2 — What this project actually is

## The one-paragraph version

This directory contains the **electronics** for the Smart Maternity Band: a
100 × 70 mm, four-layer prototype carrier PCB built around an
**ESP32-S3-WROOM-1-N8R2**, carrying an **AD8232** single-lead ECG front end, an
**LSM6DSOX** 6-axis IMU, an **AS5600** magnetic angle sensor, a **TMP117**
temperature sensor, an **HX711** load-cell ADC, four FSR channels, a stretch
sensor channel, a piezo fetal-movement channel, a vibration motor and buzzer
driver pair, an SOS button, a microSD header, and a **TP4056 + AP2112K-3.3**
Li-Po charge-and-regulate power section. It is a complete verified component
library, a seven-sheet schematic, a placed and largely routed board, and about
eighteen documents explaining every decision — all **generated from a single
Python model** so that nothing can drift out of step.

## The problem it solves

**SIH26113** asks for a maternity assist device. The wider Smart Maternity
Band concept is a dual-layer wearable that combines:

- **mechanical support** — lumbar and abdominal load relief, which is where the
  load cell, the FSR array, the stretch sensor and the angle sensor come in;
- **continuous monitoring** — maternal ECG / heart rate, temperature, posture
  and activity, plus fetal movement.

This board is the electronics pod for that. The parent repository holds the
concept website; this subdirectory is the hardware.

## The seven functional blocks

They map 1:1 onto the seven schematic sheets **and** onto the seven placement
zones on the board. That is deliberate — it means a signal you find on sheet 4
is physically in zone Z3, and you can follow it with your eyes.

| # | Block | Sheet | Zone | Implementation |
|---|---|---|---|---|
| 1 | **Power entry / charging / regulation** | 1 | Z1 (4,4)–(32,36) | Li-Po via JST-PH (`J1`), 5 V charge input (`J2`), **TP4056** charger at 500 mA, **AP2112K-3.3** 600 mA LDO, battery-voltage sense to ADC, fuel-gauge breakout header (`J4`) |
| 2 | **Central MCU** | 2 | Z2 (1,40)–(34,70) | **ESP32-S3-WROOM-1-N8R2** — Wi-Fi + BLE 5, 8 MB flash, 2 MB quad PSRAM, native USB-Serial-JTAG; RESET and BOOT buttons, UART header, two status LEDs |
| 3 | **ECG analog front end** | 4 | Z3 (66,4)–(98,40) | **AD8232** three-electrode configuration with driven right-leg (RLD), two-pole high-pass, gain 1100, per-electrode DC leads-off detection |
| 4 | **I²C sensors** | 3 | Z4 (34.5,31)–(63,49) | **TMP117** temperature, **LSM6DSOX** 6-axis IMU with both interrupts, **AS5600** magnetic angle sensor **on a separate I²C bus** |
| 5 | **Mechanical sensing** | 5 | Z5 (34.5,4)–(63,30) | **HX711** load-cell ADC, 4 × FSR dividers, stretch-sensor divider, piezo conditioning with over-voltage clamps, hall/limit input |
| 6 | **FET-driven alerts** | 6 | Z6 (66,50)–(98,68) | Two N-FET low-side drivers — vibration motor on `VBAT`, buzzer on `3V3` — each with a flyback diode and a fail-safe gate pull-down |
| 7 | **User input / storage** | 7 | Z7 (34.5,50)–(63,68) | SOS button with RC debounce and ESD series resistor, microSD SPI module header |

Plus **19 test points** and **four M2 mounting holes**.

## The numbers, at a glance

| Metric | Value |
|---|---|
| Board outline | **100 × 70 mm** (70 cm²) |
| Copper layers | **4** — L1 signal / **L2 GND plane** / **L15 3V3 plane** / L16 signal |
| Board thickness | 1.6 mm FR-4 |
| Outer copper | 1 oz (35 µm) |
| Schematic sheets | **7** |
| Parts in the model | **167** (150 placed on the board; the difference is supply symbols, which are schematic-only) |
| Library symbols | 28 |
| Library footprints | **23** |
| Library devices | 30 |
| Nets | **84** |
| Pin connections | **420** |
| Test points | 19 |
| Mounting holes | 4 × M2 |
| Track segments emitted | **4 523** |
| Vias | **486** (160 plane-connect, 15 thermal / exposed-pad, rest from routing) |
| Signal nets fully routed | **76 of 80 (95 %)** |
| BOM line items | **75** |
| Measured minimum copper clearance | **0.130 mm** |

## Why it looks like a Python project

Because it is one. There is no EDA software installed where these files were
produced, so instead of drawing a schematic by hand, the project **describes**
the design in `scripts/design.py` and generates the EAGLE files from it.

That started as a constraint and turned into the best thing about the project:

> One model produces the library, the schematic, the board, the netlist
> document, the GPIO table, the BOM, the ERC report, the DRC report, the
> statistics and the renders. **They cannot disagree with each other.**

And the generators verify themselves:

- `generate_schematic.py` **re-parses its own output** and asserts the emitted
  netlist matches the model exactly.
- `generate_board.py` does the same for elements and signals.
- `render.py` draws only primitives it finds by parsing the real `.sch` and
  `.brd` — **so a render cannot show something the board does not have.**

If the model and the files ever diverge, the build **fails** rather than
quietly emitting something wrong.

Full explanation in [Part 6](#part-6--the-generated-from-source-model).

## Three things the architecture diagram got wrong

The input to this whole project was a single architecture image
(`reference/PCB_architecture_source.jpeg`). It was treated as a **starting
point, not as truth** — and it had real bugs. The three biggest:

### 1. An I²C address clash that cannot work

The diagram puts TMP117, LSM6DSOX, AS5600 **and** MAX17048 on one shared bus.

> 🔴 **The AS5600 and the MAX17048 are both hard-wired to address `0x36`, and
> neither has an address-select pin.** Two devices at the same address on the
> same bus is not a performance problem; it is a bus that does not function.

**Resolved** with two physically separate busses, using both of the ESP32-S3's
I²C controllers:

| Bus | Pins | Devices |
|---|---|---|
| **SENSOR** (I2C0) | `IO15` / `IO16` | TMP117 `0x48`, LSM6DSOX `0x6A`, fuel-gauge header `0x36` |
| **ANGLE** (I2C1) | `IO14` / `IO42` | AS5600 `0x36`, plus `J6` for a second one |

A *second* AS5600 still clashes with the first, and that is acknowledged rather
than hidden: `J6` carries the angle bus **plus a fifth pin to `IO3` through a
DNP 0 Ω link (`R17`)**, so you can use the second sensor's analog output, an
external TCA9548A mux, or a software bus — without the board committing you to
one. Full reasoning: `DESIGN_ASSUMPTIONS.md` §5.

### 2. "TP4056 protected module" hid a missing safety circuit

See 🔴 **B1** in Part 1. The diagram's word *protected* referred to a purchased
module's DW01A + FS8205A, which a bare-IC implementation does not have.

### 3. It implied two layers would do

They do not. Measured, not assumed:

| Layers | Nets the router completed (of 81 at the time) |
|---|---|
| 2 | **~50**, and the board's reachable copper split into disconnected regions |
| 4 | **77** |

The AD8232 amplifies a sub-millivolt biopotential by 1100 across 10 MΩ nodes,
and its datasheet asks for a ground plane. With 81 signal nets and 15
through-hole connectors, two layers leaves **no continuous reference under the
analog section**. Cost of going to four layers: a couple of dollars per
prototype board. Full evidence: `DESIGN_ASSUMPTIONS.md` §2.

All seven documented architecture changes are in
[Part 25](#part-25--the-seven-architecture-changes).

---

# PART 3 — Exactly how complete this is

This part exists because "is it done?" is the question that gets answered
dishonestly most often in hardware projects. Here is the honest answer.

## The three levels

| Level | Meaning | Status |
|---|---|---|
| **1 — Architecture** | Blocks and intent | ✅ **Complete** |
| **2 — Electrical schematic + verified library** | Real parts, real pinouts, real values, connectivity checked | ✅ **Complete** |
| **3 — Manufacturable PCB** | Placed, routed, DRC-clean, manufacturing files out | 🟨 **Substantially complete** — geometry is DRC-clean, 4 airwires remain **by choice**, Gerbers need Fusion's CAM |

**This project is at Level 2 complete, Level 3 substantially complete.**

## ✅ What is genuinely done

### The component library

- **23 footprints, 28 symbols, 30 devices.**
- **Every pinout verified against the manufacturer's datasheet.** Not from
  memory, not inferred from the architecture picture.
- Three footprints come from the **vendor's own recommended land-pattern
  drawing** (ESP32-S3-WROOM-1, TMP117 WSON, LSM6DSOX LGA). The rest are
  **IPC-7351B Nominal (Level B)** land patterns derived from verified body
  dimensions.
- Self-check passes: every symbol pin maps to an existing pad, no orphan pads,
  no pad overlaps.

### The schematic

- **7 sheets, 167 parts, 84 nets, 420 pin connections.**
- **Every pin is on exactly one net.** No floating pins, no pin on two nets.
- An independent **11-rule-group ERC passes with 0 errors and 0 warnings**
  (7 informational notes, all explained).
- The generator re-parses its own `.sch` and asserts the netlist matches the
  model exactly. That assertion passes.

### The board

- **4 layers, 100 × 70 mm.** All **150** components placed in the seven
  functional zones.
- **Both power planes poured** (`GND` on L2, `3V3` on L15), drawn as an
  L-shape that omits the antenna corner.
- **Antenna keep-out enforced** — 20 × 6.6 mm at the top edge, no pad, via or
  track inside it, planes cut around it.
- **Exposed pads via-stitched** — 15 thermal vias, all **plated** board-level
  vias (see the defect list below for why that matters).
- **4 523 track segments, 486 vias.**
- Independent geometric DRC: **0 clearance, width, drill, placement, keep-out
  or board-edge violations.** Minimum measured copper clearance **0.130 mm**.

### Routing — and the concession that was made deliberately

**76 of 80 signal nets routed (95 %).** The remaining 4 are **airwires by
choice, not routing failures.**

> **Clearance is prioritised over completeness.** Where the router could only
> finish a net by coming closer than the 0.15 mm rule, it **rips the net out
> and leaves an airwire** instead.
>
> An airwire is **visible in Fusion the moment the board opens** and is a
> minute's work to route by hand. A 0.05 mm gap is **invisible** and might
> reach fabrication.

The four, with the gap each would have needed:

| Net | Came within | Of | Layer |
|---|---|---|---|
| `I2C_SDA` | 0.075 mm | `FSR1_ADC` | 1 |
| `SD_CS` | 0.090 mm | `LED_ALERT` | 1 |
| `SD_MISO` | 0.145 mm | `ESP_EN` | 1 |
| `ESP_EN` | 0.145 mm | `PIEZO_ADC` | 1 |

Finishing them is **step 13** of the build guide and should take under half an
hour — every one is a short connection whose two ends are already fanned out.

### The independent design review

`documentation/FINAL_REVIEW.md` is a second-pass review against **27 specific
failure modes**. It found and fixed **10 real defects** and left 5 items open
and documented. Those ten are worth knowing about because they show what the
review was actually for:

| Defect found | Why it mattered |
|---|---|
| **Unplated holes drilled through thermal pads** | EAGLE's `<hole>` inside a package is an **unplated** mechanical hole. Through a thermal land that is a defect — a hole with no barrel conducts no heat and breaks the pad. Moved to board-level **plated** vias. |
| **Clearance measured as a diamond, not a disc** | The obstacle dilation used Manhattan distance, so diagonal clearances were overstated by up to √2. Replaced with a Euclidean disc. |
| **Fan-out stubs crossing neighbouring pads** | Escape tracks were being drawn straight across an adjacent pad — a short. |
| **Plane-via spurs crossing neighbouring pads** | Same failure in the plane-connection code path. |
| **Rip-up cascading damage** | A non-transactional rip-up took the unrouted count from 4 to **33** while the counter still claimed success. Fixed with snapshot/restore and a recount from final state. |
| 🔴 **SOT-23-5 land pattern shorted VIN to GND** | The pad length and width were swapped, putting 1.10 mm pads on a 0.95 mm pitch. **This is the LDO.** It looked perfectly plausible in the library editor. |
| **LGA-14 land enlargement closed corner pairs to 0.11 mm** | IPC enlargement on a 0.5 mm LGA pushed corner pads together. Reverted to 1:1 with the package pad. |
| **The DRC measured round pads as squares** | Overstated clearance violations near every through-hole pad, masking real ones. |
| **The clearance model assumed every conductor was nominal width** | A 0.50 mm power track was checked as if it were 0.20 mm. |
| **Placement collisions from hand-picked coordinates** | Replaced with a resolver that enforces a 0.90 mm courtyard gap. |
| 🔴 **Plane vias placed outside the pour outline** | The pours are L-shaped — for x < 29.5 they stop at y = 63.0 to stay clear of the antenna. Two `GND` vias sat *above* that edge, and one of them was **`C7`'s only connection to the ground plane** — the HF bypass at the module's supply pin. DRC rule D7 asked "does the pad have a via on its net?" and never asked whether the via lands inside the pour. Found by `validate_planes.py`. |

That SOT-23-5 one is the reason this project has an independent review at all.

## ❌ What has NOT been done — stated plainly

| Item | Status |
|---|---|
| Autodesk EAGLE / Fusion **ERC** | ❌ **NOT EXECUTED — TOOL UNAVAILABLE.** No EAGLE installation existed. An independent ERC was written and run instead. |
| Autodesk EAGLE / Fusion **DRC** | ❌ **NOT EXECUTED — TOOL UNAVAILABLE.** An independent geometric DRC was written and run instead. |
| **Copper-pour geometry** | 🟨 **PARTLY CLOSED.** `scripts/validate_planes.py` now *measures* pour connectivity — it punches an antipad around every through-hole and via, labels connected regions, and checks every plane-net contact lands in the main one. Both pours: **one dominant region ≥ 99.9 %, ECG zone entirely inside it, 0 orphans.** **This check found a real defect** (`C7`'s ground via outside the pour). EAGLE's *exact* fill is still computed on load — run `RATSNEST`. |
| **Gerber / drill files** | ❌ **NOT GENERATED.** Needs EAGLE's CAM processor. |
| **3D / mechanical interference** | ❌ **NOT CHECKED.** No STEP models are attached to these footprints. A height table and an isometric extrusion exist instead. |
| **USB pair impedance** | ✅ **CALCULATED** — `documentation/USB_PAIR_ANALYSIS.md`. ≈ 165 Ω, not 90 Ω, but electrically short by 2.6× at Full Speed so it is not a functional risk. |
| **Component availability** | ❌ **NOT VERIFIED.** Distributor stock could not be checked. `BOM.csv` carries empty Supplier / Supplier PN / Lifecycle columns rather than invented ones. |
| **Physical prototype** | ❌ **NOT BUILT.** **No figure in this project is a measurement.** Every current, voltage and frequency is a datasheet typical or a calculation. |

> **Nothing here is claimed as passing a tool that was never run.**

## The verification summary table

| Check | Tool | Result |
|---|---|---|
| Library model consistency | `generate_library.py` | ✅ PASS |
| Schematic vs. model | `generate_schematic.py` | ✅ PASS — 84 nets, 420 pinrefs, exact match |
| ERC, 11 rule groups | `validate_erc.py` | ✅ **0 errors, 0 warnings** |
| Board vs. model | `generate_board.py` | ✅ PASS — 150 elements, 84 signals |
| DRC, 8 rule groups | `validate_drc.py` | ✅ **0 geometry violations**; min clearance **0.130 mm**. The 4 reported errors are all unrouted nets |
| Routing | `generate_board.py` | 🟨 **76 / 80 (95 %)**, 4 deliberate clearance concessions |
| Independent design review, 27 failure modes | `FINAL_REVIEW.md` | ✅ 10 defects found and fixed, 5 open and documented |
| EAGLE / Fusion ERC | — | ❌ NOT EXECUTED |
| EAGLE / Fusion DRC | — | ❌ NOT EXECUTED |

## What "finishing" this project looks like

**The design work is essentially complete.** What remains is entirely things
that cannot be done from a text editor: decisions, purchases, a licensed EDA
tool, a soldering iron, and a person.

### The critical path, with what each phase is actually blocked on

| # | Phase | Effort | **Blocked on** | Where |
|---|---|---|---|---|
| 1 | 🔴 **Clear the 3 BLOCKING items** | **~1 hour** | buying a **protected** Li-Po; **writing down** the ECG protocol; **picking** a motor | [Part 1](#part-1--the-blockers-read-this-before-anything-else) |
| 2 | 🟠 **Clear H2–H6** | **~1 hour** | picking the stretch sensor, load cell and switch; **a fab quote at 5 mil** | [Part 1](#part-1--the-blockers-read-this-before-anything-else) |
| 3 | Open in Fusion, run **its** ERC + DRC | **half a day** | Fusion installed | [Part 19](#part-19--workflow-d-open-it-in-autodesk-fusion-all-20-steps), steps 6 & 15 |
| 4 | Finish the remaining airwires by hand | **~30 min** | step 3 done first | Part 19, step 13 |
| 5 | Generate + **inspect** Gerbers, drill, paste | **~1 hour** | Fusion's CAM processor | Part 19, step 19 |
| 6 | Order PCBs + **stencil** + parts | 1 hour, then **1–3 weeks lead** | 🟠 **H5 and H6 settled first** | [Part 20](#part-20--workflow-e-order-the-pcb) |
| 7 | Assemble | **1 day** | stencil + reflow or hot air | [Part 21](#part-21--workflow-f-assemble-the-board) |
| 8 | Bring-up, six stages | **2 days** | boards in hand | [Part 22](#part-22--workflow-g-bring-up-in-six-stages) |
| 9 | Firmware | **weeks** | — | [Part 23](#part-23--workflow-h-firmware) |

### The dependency order, because two of these are easy to get wrong

```
  B1/B2/B3  ──────────────┐
  (decisions, ~1 h)       │
                          ▼
  H5 (-N8R2) ────────►  ORDER PARTS ──────┐
  H6 (5 mil) ────────►  ORDER PCBs ───────┤  1-3 weeks lead
  H4 (switch grid) ──►  + STENCIL  ───────┘        │
                                                   ▼
  Install Fusion ──► ERC ──► finish airwires ──► DRC ──► GERBERS
       (step 3)                 (step 4)              (step 5)
                                                   │
                                                   ▼
                              ASSEMBLE ──► BRING-UP ──► FIRMWARE
                               (1 day)      (2 days)     (weeks)
```

> 🟠 **The two easy mistakes, both one dropdown each:**
> **H5** — ordering `-N8R8` instead of `-N8R2`, which kills the ECG channel.
> **H6** — accepting the fab's default 6 mil, which this board fails at
> 0.130 mm measured clearance.
>
> 🔵 **And note steps 5 and 6 are independent of each other.** You can order
> PCBs from the Gerbers only *after* step 5, but you can order the **parts**
> as soon as H5 is settled. Do that early — the AD8232 is occasionally
> allocated (⚪ L4).

### Realistically

| | |
|---|---|
| **Today, at a desk** | steps 1 and 2 — all decisions and purchases, ~2 hours total |
| **This week** | steps 3–5 — Fusion, airwires, Gerbers. About a day of real work |
| **Then 1–3 weeks** | waiting on the fab |
| **Then ~3 days** | assemble and bring up |
| **Then weeks** | firmware |

---

# PART 4 — Absolute-beginner setup

This part assumes **nothing**. If you already have Python and Fusion, skip to
[Part 5](#part-5--every-single-file-explained).

## 4.1 — What you actually need, and when

There are three completely separate toolchains here, and **you do not need all
of them.** Work out which one you are in.

| I want to… | I need | I do **not** need |
|---|---|---|
| **Read and understand the design** | a Markdown viewer and an image viewer. That's it. | Python, Fusion, anything else |
| **Regenerate the files after changing something** | Python 3.11+ with numpy, matplotlib, Pillow | Fusion |
| **Open, inspect, finish and manufacture the board** | Autodesk Fusion (Electronics) | Python |
| **Write the firmware** | ESP-IDF or Arduino-ESP32, and a USB-serial cable | Python, Fusion |
| **Assemble the board** | soldering gear, a stencil, a hotplate or hot-air station | all software |

**Nobody needs all four at once.** Pick the one matching what you are doing
today.

## 4.2 — Getting the files

```bash
git clone <your-repository-url>
```

Then:

```bash
cd Smart-India-Hackaton/SIH26113_Maternity_Assist_Belt
```

Everything for the PCB lives in that one directory. Nothing outside it belongs
to this work.

**If you were handed a ZIP instead:** unzip it somewhere with **no spaces and
no non-ASCII characters in the path**. `C:\work\sih\` is fine.
`C:\Users\Ayşe's Files\New folder (2)\` will cause problems with some EDA
tooling.

## 4.3 — A Markdown viewer (5 minutes, everyone needs this)

Every document in this project is Markdown. You can read them in Notepad, but
you will have a bad time — the tables will be unreadable.

**Pick one:**

| Option | How | Notes |
|---|---|---|
| **VS Code** (recommended) | install it, open the folder, press <kbd>Ctrl</kbd>+<kbd>Shift</kbd>+<kbd>V</kbd> on any `.md` file | free, cross-platform, also gives you the Python tooling later |
| **GitHub / your Git host** | just browse the repo in a browser | renders the 🔴/🟠 alert blocks properly, which local viewers may not |
| **Typora / Obsidian / MarkText** | open the folder | fine |
| **Any browser + a Markdown extension** | — | fine |

> **Note on the coloured blocks in this document.** The 🔴 red and 🟠 orange
> callouts use GitHub's alert syntax (`> [!CAUTION]`, `> [!WARNING]`) plus
> LaTeX-coloured headings plus emoji. **GitHub renders all three.** Local
> viewers render at least the emoji and the bold. If you see literal
> `[!CAUTION]` text, your viewer does not support alerts — the content is still
> correct, just less shouty. Read Part 1 anyway.

## 4.4 — Python, for regenerating the project

**Only needed if you are going to change the design.** If you are just opening
the existing `.brd` in Fusion, skip this.

### Check whether you already have it

```bash
python --version
```

You want **3.11 or newer**. The project was developed and last run on **Python
3.14.6**. If you get "command not found" or a 2.x/3.8 version, install a
current Python.

### Install Python

| OS | How |
|---|---|
| **Windows** | download from [python.org](https://www.python.org/downloads/) and **tick "Add python.exe to PATH"** during install. Or `winget install Python.Python.3.13` |
| **macOS** | `brew install python@3.13` |
| **Linux (Debian/Ubuntu)** | `sudo apt install python3 python3-pip python3-venv` |

### Install the three dependencies

```bash
python -m pip install numpy matplotlib Pillow
```

Versions last verified working:

| Package | Version | Used by |
|---|---|---|
| `numpy` | 2.5.3 | `router.py` — the occupancy grid and the Euclidean-disc dilation |
| `matplotlib` | 3.11.1 | `render.py` — all 12 PNGs |
| `Pillow` | 12.3.0 | `render.py` — image handling |

**Nothing else is required.** No EDA library, no external binary, no network
access. The EAGLE XML is written with Python's standard library.

### Recommended: use a virtual environment

Keeps this project's packages away from the rest of your system.

```bash
python -m venv .venv
```

Then activate it:

| Shell | Command |
|---|---|
| Windows PowerShell | `.\.venv\Scripts\Activate.ps1` |
| Windows cmd | `.\.venv\Scripts\activate.bat` |
| Git Bash / macOS / Linux | `source .venv/bin/activate` |

Then `python -m pip install numpy matplotlib Pillow`.

### Verify it works

```bash
python scripts/generate_library.py
```

You should see the library self-check pass and
`libraries/SIH26113_Maternity_Assist_Belt.lbr` be rewritten. If that works,
your Python setup is complete.

> **What goes wrong:** `ModuleNotFoundError: No module named 'numpy'` means the
> virtual environment is not active, or you installed into a different Python
> than the one running the script. Check with
> `python -c "import sys; print(sys.executable)"`.

## 4.5 — Autodesk Fusion (Electronics), for the PCB work

### What to install

**Autodesk Fusion.** The Electronics workspace — what used to be sold as
EAGLE — is built into it. The **free personal-use licence includes
Electronics**, which is enough for this entire project.

1. Go to Autodesk's Fusion page and choose the **personal / hobbyist** licence.
2. Create an Autodesk account (free).
3. Download and install. It is a large install; budget 30–60 minutes.
4. Launch it and sign in.
5. Switch to the **Electronics** workspace.

### 🟠 Version compatibility — this matters

| Tool | Reads these files? |
|---|---|
| **Autodesk Fusion** (any current version) | ✅ yes |
| **Autodesk EAGLE 9.x** standalone | ✅ yes |
| **EAGLE 7.x** or older standalone | ❌ **no** — these files use the EAGLE 9 XML format |
| KiCad | ⚠️ partially — KiCad can import EAGLE libraries and schematics, with losses. Not the intended path and not tested. |

If Fusion offers **"Migrate EAGLE project"**, say **yes**.

### What you do NOT need to buy

- No Fusion Electronics paid tier. The personal licence handles a 100 × 70 mm
  4-layer board.
- No third-party libraries. The library is included, and the `.sch` and `.brd`
  each carry a **full embedded copy** of it — so they open correctly even if
  you never import the `.lbr` separately.

## 4.6 — Firmware toolchain

**Only needed once you have hardware.** Two choices:

| Option | Install | Best for |
|---|---|---|
| **ESP-IDF** (recommended) | Espressif's installer, or the VS Code ESP-IDF extension | full control, real projects, proper ADC calibration |
| **Arduino-ESP32** | Arduino IDE → Boards Manager → "esp32 by Espressif" | fastest to a blinking LED |

Board selection: **ESP32S3 Dev Module** with **8 MB flash** and **QSPI
PSRAM enabled**.

### 🟡 Serial port note

This board's `J2` USB header goes to the ESP32-S3's **native USB-Serial-JTAG**
on `IO19`/`IO20`. That means:

- **No CP2102 / CH340 driver is needed.** The MCU *is* the USB device.
- On Windows it appears as a **USB Serial Device (COMx)**. On Linux,
  `/dev/ttyACM0`. On macOS, `/dev/cu.usbmodem*`.
- If it does not appear at all, `J5` (the 6-way UART header) is the documented
  fallback path — see 🟡 M2 and [Part 24](#part-24--troubleshooting-encyclopedia).

## 4.7 — Bench and assembly gear

Listed here so you can order it early — some of it has lead time.

### Minimum to bring up the power stage safely

| Item | Why | Notes |
|---|---|---|
| **Bench power supply with current limit** | 🔴 the single most useful safety tool you can own | set 5 V, limit 100 mA for first power-on. A short shows as the limit engaging, not as smoke. |
| **Multimeter** | measuring `TP1`–`TP4`, and 🔴 **B1's polarity check** | any meter |
| **Fine-tip soldering iron**, 0.4–0.8 mm chisel | everything through-hole and 0805 | temperature-controlled |
| **Solder wick + flux** | you will need both | no-clean flux |
| **Tweezers**, fine | placing 0805s | ESD-safe |

### Required for the three fine-pitch parts

> 🟠 **The AD8232, LSM6DSOX and TMP117 cannot be soldered with an iron.**

| Item | Why |
|---|---|
| **Solder-paste stencil** | order it **with the boards** — see [Part 20](#part-20--workflow-e-order-the-pcb). This is the item people forget. |
| **Leaded solder paste** (Sn63Pb37) or SAC305 | leaded is more forgiving by hand |
| **Hotplate or reflow oven**, *or* a **hot-air rework station** | either works |
| **Stencil jig / frame**, or tape and a stiff card | to hold the stencil aligned |

### Very useful

| Item | Why |
|---|---|
| **Oscilloscope** | 🔵 essentially required for the ECG stage. `TP10` (`ECG_OUT`) and `TP11` (`ECG_REFOUT`) are there specifically for this. |
| **USB microscope** or a loupe | inspecting 0.5 mm-pitch solder joints |
| **Logic analyser** | I²C debugging on `TP18`/`TP19` |
| **ECG electrodes**, disposable Ag/AgCl, 3 off | for `J7` |
| **Diametric NdFeB magnet**, ~6 × 2.5 mm | for the AS5600 — see 🟡 M6 |

## 4.8 — A five-minute sanity check that everything is set up

Run these in order. Each should succeed.

```bash
python --version
```

```bash
python -c "import numpy, matplotlib, PIL; print('deps ok')"
```

```bash
python scripts/validate_erc.py
```

That last one should end with `RESULT: PASS` and `--- ERRORS (0) ---`. If it
does, you have a working Python environment and a valid design model.

```bash
python scripts/validate_drc.py
```

This one ends with `RESULT: FAIL` — **and that is expected.** The four
"errors" are the four deliberately-unrouted nets. Read
[Part 15](#part-15--verification-what-was-checked-and-how) before you worry
about it.

---

# PART 5 — Every single file, explained

There are 54 files. This part covers **all** of them: what it is, why it
exists, when you would read it, and whether it is hand-written or generated.

## 5.1 — The directory tree

```
SIH26113_Maternity_Assist_Belt/
│
├── README.md                      ← the short entry point
├── FULL_INSTRUCTION_TUTORIAL.md   ← this document
│
├── libraries/
│   └── SIH26113_Maternity_Assist_Belt.lbr    EAGLE 9 / Fusion library
│
├── schematic/
│   └── SIH26113_Maternity_Assist_Belt.sch    7 sheets
│
├── pcb/
│   ├── SIH26113_Maternity_Assist_Belt.brd    4-layer board
│   ├── route_report.json                     the router's own output
│   ├── drc_result.json                       DRC findings, machine-readable
│   └── plane_result.json                     plane-pour connectivity
│
├── fusion_project/           ← OPEN THIS IN FUSION
│   ├── *.lbr + *.sch + *.brd  the three files together, same base name,
│   │                          because EAGLE pairs a schematic with a board
│   │                          by filename AND directory  (see 5.8)
│   └── README.md
│
├── documentation/            18 documents — see 5.3
│
├── renders/                  12 PNGs — see 5.4
│
├── reference/
│   └── PCB_architecture_source.jpeg          the input architecture diagram
│
└── scripts/                  16 Python files — see 5.5
```

## 5.2 — The three EDA files (the actual deliverables)

### `libraries/SIH26113_Maternity_Assist_Belt.lbr`

**What:** the EAGLE 9 / Fusion component library. XML, human-readable if you
open it in a text editor.

**Contains:** 23 packages (footprints), 28 symbols (schematic representations),
30 devicesets (the pairing of a symbol with a footprint, plus pin-to-pad
mapping and part attributes).

**Why it exists separately:** so you can place *new* parts from it. The `.sch`
and `.brd` each carry a **full embedded copy**, so they open correctly even if
you never import this file.

**When you touch it:** you don't — it is generated by
`scripts/generate_library.py`. If you need a new footprint, edit
`scripts/lib_defs.py` and re-run.

**How to inspect it:** Fusion → Library Manager → Import. Or read the XML: it
is genuinely legible, and `<package>`, `<symbol>` and `<deviceset>` blocks are
easy to follow.

### `schematic/SIH26113_Maternity_Assist_Belt.sch`

**What:** the seven-sheet schematic.

| Sheet | Title |
|---|---|
| 1/7 | POWER ENTRY, CHARGING AND 3V3 REGULATION |
| 2/7 | ESP32-S3 CENTRAL MCU, RESET/BOOT, PROGRAMMING, INDICATORS |
| 3/7 | I2C SENSORS (TMP117, LSM6DSOX, AS5600) — TWO BUSSES |
| 4/7 | ECG ANALOG FRONT END (AD8232) |
| 5/7 | MECHANICAL SENSING (LOAD CELL, FSR, STRETCH, PIEZO, HALL) |
| 6/7 | FET-DRIVEN ALERTS (VIBRATION MOTOR, BUZZER) |
| 7/7 | USER INPUT AND STORAGE (SOS, microSD) |

**167 parts, 84 nets, 420 pin connections.**

**Generated by:** `scripts/generate_schematic.py`, which then **re-parses its
own output** and asserts the emitted netlist matches the model exactly.

**When you touch it:** never by hand. Edit `design.py`.

### `pcb/SIH26113_Maternity_Assist_Belt.brd`

**What:** the four-layer board.

| Property | Value |
|---|---|
| Outline | 100 × 70 mm on layer 20 |
| `layerSetup` | `(1*2*15*16)` |
| Elements | **150** |
| Signals | **84** |
| Wires | **~4 523** |
| Vias | **486**, all through-hole (`extent="1-16"`) |
| Plane polygons | 2 — `GND` on L2, `3V3` on L15 |
| Design-rule set | `SIH26113_4layer` with `mdWireWire=0.127mm`, `msWidth=0.15mm`, `msDrill=0.3mm` |

**Generated by:** `scripts/generate_board.py`, which places, routes and emits,
then re-parses and cross-checks elements and signals.

## 5.3 — `documentation/` — all 18 documents

Ordered by when you would actually read them.

| # | File | Lines | Written or generated | What it is, and when to read it |
|---|---|---|---|---|
| 1 | 🔴 **`REQUIRES_CONFIRMATION.md`** | 324 | hand-written | **Read this first, before anything else.** Every open item, ordered by consequence: **3 BLOCKING, 6 HIGH, 5 MEDIUM (M2 and M5 now resolved), 5 LOW**, plus a table of items resolved during design so they are not re-opened. Reproduced and expanded in [Part 1](#part-1--the-blockers-read-this-before-anything-else). |
| 2 | **`FINAL_REPORT.md`** | 243 | generated | The single-document summary: what was created, exact file list, components and variants, unresolved components, assumptions, ERC status, DRC status, net and component counts, dimensions, layers, risks, what needs physical verification, and the exact next steps in Fusion. **If you read only one document, read this one.** |
| 3 | **`PCB_BUILD_GUIDE.md`** | ~522 | hand-written | 20 numbered steps from installing Fusion to ordering boards, each with **Do / Check / What goes wrong**. Plus the six-stage bring-up order and the regeneration commands. Expanded in [Part 19](#part-19--workflow-d-open-it-in-autodesk-fusion-all-20-steps). |
| 4 | **`DESIGN_ASSUMPTIONS.md`** | 556 | hand-written | **The most important document for understanding *why*.** 15 numbered sections covering power architecture, the four-layer decision with measured evidence, board size, module variant, the two-I²C-bus resolution, the ECG front end, mechanical sensing, alerts, GPIO constraints, grounding, microSD, USB, protection, placement strategy, and "things I would do differently". Contains all seven **[ARCHITECTURE CHANGE]** markers. |
| 5 | **`COMPONENT_VERIFICATION.md`** | 210 | hand-written | Every part, its verification level, and **the specific document the pinout came from**. Explains how the datasheets were read (including rasterising vector-only drawings at 5× to read dimensions from figures). Sections A–G by part category. Read this if you doubt any pinout. |
| 6 | **`GPIO_ASSIGNMENT.md`** | 66 | generated | All 41 module pins: pad number, function, net, direction, boot-criticality, ADC channel, peripheral, what it connects to, and notes. Plus the pin budget and the strapping-pin analysis. **Essential for firmware.** |
| 7 | **`POWER_BUDGET.md`** | 191 | hand-written | Itemised current budget per rail with the source of every figure, the dropout analysis that produces the 🔵 3.5 V cut-off requirement, charging figures, trace-width justification with IPC-2221 arithmetic, and a deep-sleep estimate. |
| 8 | **`ECG_FRONTEND_DESIGN.md`** | 381 | hand-written | The AD8232 circuit with all the arithmetic: signal chain, supply-rail constraint, patient protection, three-electrode DC leads-off, right-leg drive, reference network, the two-pole high-pass and its factor of 100, the low-pass and gain, source-impedance interaction, resulting response, and the firmware requirements the circuit imposes. |
| 9 | **`USB_PAIR_ANALYSIS.md`** | ~180 | hand-written | The USB differential pair, calculated. Closes 🟡 M2. As-routed ≈ 165 Ω vs the 90 Ω USB asks for, why that is not a functional risk at Full Speed, and the geometry that *would* give 90 Ω. |
| 10 | **`GROUNDING_NOTES.md`** | 219 | hand-written | Why **one** ground net and not a split AGND/DGND, with three specific arguments. Stack-up, placement separation, motor return-current confinement, via stitching, and why the antenna keep-out cuts *all* copper including planes. |
| 11 | **`NETLIST.md`** | 111 | generated | All 84 nets: type, voltage, source, loads, routing status, notes. |
| 12 | **`BOM.md`** | 129 | generated | 75 line items, 150 placements, grouped by value. Manufacturer PNs from datasheet ordering guides. Plus placements-by-package with assembly method, an assembly note, and **"parts NOT on this board"** with the reason for each. |
| 13 | **`BOM.csv`** | — | generated | Machine-readable BOM with three deliberately-empty columns: **Supplier**, **Supplier PN**, **Lifecycle**. See ⚪ L4. |
| 14 | **`ERC_REPORT.md`** | 62 | generated | The 11 rule groups, the full run output (**0 errors, 0 warnings, 7 notes**), and a table of intentional exceptions with why each is acceptable. Leads with the ❌ NOT EXECUTED note about EAGLE's own ERC. |
| 15 | **`DRC_REPORT.md`** | 158 | generated | The 8 rule groups, stack-up as emitted, the clearance rules and the one declared exception, the full run output, routing completeness, the four deliberately-unrouted nets with the gap each would have needed, and what has *not* been verified. |
| 16 | **`MANUFACTURING_CHECK.md`** | 83 | generated | The 19-point pre-fab check with the value the files actually contain. Plus connector accessibility, assembly feasibility, and the mechanical height envelope. |
| 17 | **`FINAL_REVIEW.md`** | 440 | hand-written | The independent second-pass review: **10 defects found and fixed** (each with what it was and why it mattered), then the **27-point review** against specific failure modes with ✅ / ⚠️ per item. |
| 18 | **`PROJECT_STATISTICS.md`** | 77 | generated | Counts and metrics, placements by footprint, and the test-point table. |

> The machine-readable companions to these live in `pcb/`: `route_report.json`, `drc_result.json` and `plane_result.json`.

### The two machine-readable files in `pcb/`

| File | What it is |
|---|---|
| `route_report.json` | the router's own output: per-net status, the reason for each unrouted net, attempt counts, the winning seed |
| `plane_result.json` | plane-pour connectivity per layer per pass: region count, areas, orphaned contacts, ECG-zone membership |
| `drc_result.json` | every DRC finding as structured data, so you can diff it between runs |
| `plane_result.json` | plane-pour connectivity per layer per pass: region count, areas, orphaned contacts, ECG-zone membership |

## 5.4 — `renders/` — all 12 PNGs

**Every one of these is drawn by parsing the real `.sch` / `.brd`** and
rendering the primitives found there. A render **cannot** show something the
files do not contain. That is the point.

| File | What it shows | Use it for |
|---|---|---|
| `schematic_p1.png` | Sheet 1 — power entry, charging, regulation | reviewing the power section without opening Fusion |
| `schematic_p2.png` | Sheet 2 — ESP32-S3 core | checking the module wiring |
| `schematic_p3.png` | Sheet 3 — I²C sensors, both busses | verifying the two-bus split |
| `schematic_p4.png` | Sheet 4 — ECG front end | following the AD8232 signal chain |
| `schematic_p5.png` | Sheet 5 — mechanical sensing | FSR / load cell / piezo / stretch / hall |
| `schematic_p6.png` | Sheet 6 — FET-driven alerts | checking flyback polarity by eye |
| `schematic_p7.png` | Sheet 7 — user input and storage | SOS and microSD |
| `pcb_top.png` | Layer 1 copper, pads, silkscreen | seeing the top-side routing density |
| `pcb_bottom.png` | Layer 16 copper | seeing how much emptier the bottom is |
| `pcb_layers.png` | **all four copper layers** side by side | understanding the stack-up and the plane cut-outs |
| `pcb_assembly.png` | placement + reference designators + zone boxes | **the most useful one for assembly** — print it |
| `pcb_3d.png` | isometric mechanical envelope from the height table | sizing an enclosure, spotting a connector that fouls a lid |

> ⚠️ `pcb_3d.png` is an **extrusion of a height table**, not a solid model.
> Heights are colour-coded by source: datasheet-derived vs. typical. It is
> enough to size an enclosure; it is **not** a 3D interference check, and no
> such check has been done.

## 5.5 — `scripts/` — all 16 Python files

Detailed in [Part 7](#part-7--every-script-explained). Summary here:

| File | Lines | Role |
|---|---|---|
| ★ **`design.py`** | 1 025 | **the single source of truth.** Board dimensions, stack-up, planes, keep-outs, zones, mounting holes, escape channels, clearances, net classes, all 167 parts, all 84 nets, the GPIO table |
| **`lib_defs.py`** | 1 178 | 23 packages, 28 symbols, 30 devicesets, thermal-via definitions, the package height table |
| **`eagle_common.py`** | 592 | the EAGLE layer table, XML emitters, IPC-7351B land-pattern generators |
| **`geom.py`** | 103 | pin/pad geometry and coordinate transforms |
| **`router.py`** | 628 | the grid router: occupancy grids, Euclidean-disc dilation, 8-connected A*, transactional rip-up |
| `generate_library.py` | 175 | → `.lbr`, plus the library self-check |
| `generate_schematic.py` | 222 | → `.sch`, plus the self-cross-check |
| `generate_board.py` | 949 | place + route + emit `.brd`, plus fan-outs, repair and concession passes |
| `validate_erc.py` | 280 | the 11-group independent ERC |
| `validate_drc.py` | 421 | the 8-group independent geometric DRC |
| **`validate_planes.py`** | ~330 | **plane-pour connectivity** — antipad punching, connected-component labelling, per-contact region membership |
| `render.py` | 490 | → all 12 PNGs |
| `generate_docs.py` | 608 | → NETLIST, GPIO_ASSIGNMENT, BOM.md/csv, ERC_REPORT, DRC_REPORT, PROJECT_STATISTICS |
| `gen_reports.py` | 691 | → MANUFACTURING_CHECK (19 items), FINAL_REPORT (15 sections) |
| `make_fusion_project.py` | ~95 | → `fusion_project/` — the `.lbr`/`.sch`/`.brd` in one folder so Fusion pairs them |
| `build_all.py` | ~60 | runs all of the above in the correct order |
| `.gitignore` | 2 | ignores `__pycache__/` and `*.pyc` |

## 5.6 — `reference/PCB_architecture_source.jpeg`

The **input** to the whole project: the architecture diagram this design was
derived from.

Kept deliberately, for two reasons:

1. **Traceability.** Every deviation from it is marked
   **[ARCHITECTURE CHANGE]** in `DESIGN_ASSUMPTIONS.md`, and you can only
   check that against the original.
2. **Honesty about the starting point.** It was treated as a starting point,
   **not as truth** — and it had three real bugs (see
   [Part 2](#part-2--what-this-project-actually-is)).

## 5.7 — Which files are safe to hand-edit

| File | Hand-edit? |
|---|---|
| `scripts/design.py`, `lib_defs.py`, and the other scripts | ✅ **yes — this is where you make changes** |
| `documentation/*.md` marked hand-written | ✅ yes |
| `README.md`, `FULL_INSTRUCTION_TUTORIAL.md` | ✅ yes |
| Anything with `<!-- GENERATED by scripts/... -->` at the top | ❌ **no** — re-run the script; your edit will be overwritten |
| `.lbr`, `.sch`, `.brd` | ⚠️ you *can* edit these in Fusion, and at some point you will have to (finishing the airwires). But then **Fusion becomes the source of truth for that change** and re-running the generators will discard it. See [Part 18](#part-18--workflow-c-change-the-design) for how to handle that fork. |
| `route_report.json`, `drc_result.json`, `plane_result.json` | ❌ no |
| `fusion_project/*` | ⚠️ **these are generated copies.** Editing them is fine — that is what they are for — but `make_fusion_project.py` overwrites them from `libraries/`, `schematic/` and `pcb/`. Once you start working in Fusion, **stop running it.** See 5.8. |
| `renders/*.png` | ❌ no |

> 🟠 **The fork problem, stated early because it will bite you.** The moment
> you route an airwire in Fusion, the `.brd` contains something the model does
> not. Re-running `generate_board.py` will throw that away. Decide, and write
> it down: either **the model is authoritative** (make all changes in
> `design.py`, re-run, re-route by hand each time) or **Fusion is
> authoritative from here on** (stop re-running `generate_board.py`). Both are
> defensible. Mixing them silently is not. [Part 18.7](#187--the-fork-problem-model-vs-fusion)
> covers this properly.

## 5.8 — `fusion_project/` — the folder you actually open

**Why it exists.** EAGLE and Fusion pair a schematic with a board **by
filename and directory**: opening `foo.brd` makes the tool look for `foo.sch`
*beside it*. **No link is stored inside either file.**

This project keeps them in `schematic/` and `pcb/` because that is more
legible to read. The consequence is that opening either one from its own
folder loads it **standalone** — the schematic↔board consistency check cannot
run, and forward/back annotation is off. You would probably not notice until
an edit in one failed to appear in the other.

So `scripts/make_fusion_project.py` copies the `.lbr`, `.sch` and `.brd` into
one flat folder with a shared base name:

```bash
python scripts/make_fusion_project.py
```

It is also the **last step of `build_all.py`**, so it stays current.

| | |
|---|---|
| **Open this** | `fusion_project/SIH26113_Maternity_Assist_Belt.sch` |
| Not this | `schematic/…sch` — loads standalone |
| Canonical source | `libraries/`, `schematic/`, `pcb/` — what the generators write |
| `fusion_project/` is | **copies**, regenerated on demand |

> 🟠 **These are copies, so there are two of each file in the repository.**
> That is a deliberate trade: ~800 KB of duplication buys a folder that opens
> correctly for someone who does not have Python installed. If you would rather
> not commit it, add `fusion_project/` to `.gitignore` and run
> `make_fusion_project.py` after cloning.
>
> **The moment you edit in Fusion, `fusion_project/` becomes the authoritative
> copy** — see [Part 18.7](#187--the-fork-problem-model-vs-fusion).

---

# PART 6 — The generated-from-source model

## 6.1 — Why the project is built this way

A normal PCB project is drawn: you place symbols on a schematic canvas, wire
them, then push them into a layout editor. There was no EDA software available
in the environment where this project was produced, so it was **described**
instead — in Python — and the EAGLE files were generated from that description.

That started as a workaround. It ended up being the strongest property of the
project, for one reason:

> **One model produces the library, the schematic, the board, the netlist
> document, the GPIO table, the BOM, the ERC report, the DRC report, the
> statistics and every render. They cannot disagree with each other.**

In a hand-drawn project, the BOM drifts from the schematic, the GPIO table in
the wiki drifts from the actual netlist, and the "min clearance" figure in the
README drifts from the board. Here, all of those are derived from the same
1 025-line file. If you change a resistor value in `design.py`, the schematic,
the board, the BOM and the netlist document all change together, or the build
fails.

## 6.2 — The self-verification, which is the other half of the idea

Generating files is easy. Generating **correct** files is the problem. So each
generator checks its own output:

| Generator | What it asserts about its own output |
|---|---|
| `generate_library.py` | every symbol pin maps to an existing pad; no orphan pads; no pad overlaps within a package |
| `generate_schematic.py` | **re-parses the emitted `.sch`** and asserts the netlist extracted from it matches the model exactly — 84 nets, 420 pinrefs |
| `generate_board.py` | **re-parses the emitted `.brd`** and asserts elements and signals match the model — 150 elements, 84 signals |
| `validate_drc.py` | deliberately **shares no code with the router**, so it is capable of contradicting it |
| `render.py` | draws **only** primitives found by parsing the real `.sch` / `.brd` — a render cannot show something the files do not contain |

> That last one is worth dwelling on. In most projects a "3D render" is a
> separate artefact that can be beautiful and wrong. Here, if a track is
> missing from the `.brd`, it is missing from `pcb_top.png`. The renders are
> evidence, not marketing.

And `validate_drc.py` not sharing code with `router.py` is the reason the
"clearance measured as a diamond" defect was **found**. The router thought it
was clear; the independent DRC measured it and disagreed.

## 6.3 — `design.py` — the single source of truth

1 025 lines. Everything that defines *this* board, as opposed to how EAGLE
files are written, lives here.

### Board-level constants

```python
BOARD_W        = 100.0     # mm
BOARD_H        = 70.0      # mm
BOARD_LAYERS   = 4
BOARD_THICKNESS = 1.6      # mm FR-4
COPPER_OZ      = 1
```

### The stack-up and the planes

```python
PLANE_LAYERS = {2: "GND", 15: "3V3"}
```

EAGLE layer **2** (`Route2`) carries the solid `GND` pour; layer **15**
(`Route15`) carries the solid `3V3` pour. `layerSetup` in the emitted `.brd` is
`(1*2*15*16)`.

`PLANE_OUTLINE` is the polygon both pours use. It is **L-shaped** — it
deliberately omits the antenna corner, because:

```python
ANTENNA_KEEPOUT = (9.0, 63.4, 29.0, 70.0)   # x1, y1, x2, y2 in mm
```

> 🟡 **The keep-out cuts *all* copper, planes included.** A ground plane under
> a PCB antenna does not "shield" it — it detunes it and kills the range. This
> is why mounting hole `H3` is at (2.6, 42) instead of the top-left corner
> (⚪ L1).

### The seven placement zones

```python
ZONES = [
    ("Z1  POWER ENTRY / CHARGING / 3V3",  4.0,  4.0, 32.0, 36.0),
    ("Z2  ESP32-S3 CORE",                 1.0, 40.0, 34.0, 70.0),
    ("Z5  MECHANICAL SENSING",           34.5,  4.0, 63.0, 30.0),
    ("Z4  I2C SENSORS",                  34.5, 31.0, 63.0, 49.0),
    ("Z7  USER INPUT / STORAGE",         34.5, 50.0, 63.0, 68.0),
    ("Z3  ECG ANALOG FRONT END",         66.0,  4.0, 98.0, 40.0),
    ("Z6  FET-DRIVEN ALERTS",            66.0, 50.0, 98.0, 68.0),
]
```

Each zone corresponds 1:1 to a schematic sheet. **The ECG block (Z3) is in the
far corner from the alerts block (Z6)** — that is the placement half of the
grounding strategy (see [Part 12](#part-12--grounding-and-the-stack-up)).

### Mounting holes

```python
MOUNT_HOLES = [(3.0, 3.0), (97.0, 3.0), (2.6, 42.0), (97.0, 67.0)]
```

Three corners plus one mid-left-edge. See ⚪ L1.

### The escape channels — the most important placement constraint

```python
ESCAPE_CHANNELS = [
    (0.90, 43.0,  9.50, 64.0),    # left of the module's pad column
    (28.50, 40.0, 34.20, 64.0),   # right of the module's pad column
    (8.00, 36.00, 29.00, 44.20),  # below the module's end row
]
CHANNEL_EXEMPT = {"C7", "C8", "R7", "C10"}
```

The comment in the source says it best:

> The ESP32-S3-WROOM-1 presents **40 lands on a 1.27 mm pitch across three
> edges**; without a dedicated escape corridor outboard of each land row there
> is simply nowhere for those 40 signals to go, and the router (or a human)
> stalls. These bands are the **single most important placement constraint on
> the board.**

`CHANNEL_EXEMPT` allows the module's own decoupling (`C7`, `C8`) and its reset
network (`R7`, `C10`) inside the left channel — keeping `C7`/`C8` within ~2 mm
of module pin 2 matters more than the two track slots they cost, and both are
on a plane net anyway.

### The clearance model

```python
FINE_PITCH_CLEARANCE = 0.127   # inside a fan-out envelope
GENERAL_CLEARANCE    = 0.15    # everywhere else
EDGE_CLEAR           = 0.40    # copper to board edge
COURTYARD_GAP        = 0.90    # between component courtyards

FANOUT_ENVELOPE = {
    "AD8232":   6.6,   # half-size, mm
    "LSM6DSOX": 4.8,
    "TMP117":   4.1,
    "HX711":    8.0,
}
```

Those four envelopes are the **only** places the 0.127 mm rule applies. See
🟠 H6 for why the exception is physics rather than a fudge.

### Net classes

```python
NET_CLASSES = [
    # (id, name,         width, drill, clearance)   all mm
    (0, "default",        0.20, 0.3, 0.15),
    (1, "power",          0.50, 0.4, 0.20),
    (2, "motor",          0.50, 0.4, 0.20),
    (3, "analog_ecg",     0.20, 0.3, 0.20),
]

POWER_NETS = {"GND", "3V3", "VBAT", "VBUS"}
MOTOR_NETS = {"MOTOR_P", "MOTOR_N"}
ECG_NETS   = { ... 15 ECG nets ... }
```

`net_class(name)` maps a net name to a class id. `PROJECT_STATISTICS.md` and
`POWER_BUDGET.md` both read their track-width figures **from this table**, so
the documents cannot drift from the board. (They did once — see
[Part 26](#part-26--known-limitations-honestly).)

> **Note the signal and power widths are narrower than the 0.25 / 0.60 mm this
> design started with.** They were reduced *deliberately*: a narrower track
> needs less clearance around it, and that bought back the routing density lost
> when the clearance model was corrected to measure Euclidean distance.
> **Ampacity was never the binding constraint** — 0.50 mm carries ≈ 1.45 A
> against a 620 mA worst case, which is **2.3× margin**.

### Parts

```python
@dataclass
class Part:
    ref: str              # "R45"
    deviceset: str        # "R-0805"
    value: str            # "0R"
    desc: str             # human-readable purpose
    sheet: int            # 1..7
    sx: float; sy: float  # schematic position, mm
    srot: str = "R0"
    bx: float = 0.0       # board position, mm
    by: float = 0.0
    brot: str = "R0"
    mpn: str = ""
    manufacturer: str = ""
    package_note: str = ""
```

Parts are added with a helper that appends to a module-level list:

```python
def P(*a, **kw) -> Part:
    p = Part(*a, **kw)
    PARTS.append(p)
    return p
```

So the part list reads as a literal declaration, sheet by sheet:

```python
# ---- SHEET 4 - ECG ANALOG FRONT END ----
P("R20", "R-0805", "330k", "RLD output current limit (datasheet: >330k at 3.0 V)", ...)
```

**167 parts.** Note that 167 in the model vs **150 placed** on the board — the
difference is supply symbols (`SUPPLY1.GND` etc.), which exist on the schematic
to make power connections legible and have no physical footprint.

### Nets

```python
NETS: dict[str, list[tuple[str, str]]] = {}

def N(net: str, *conns: str) -> None:
    """Add connections written as 'REF.PIN'."""
    lst = NETS.setdefault(net, [])
    for c in conns:
        ref, pin = c.split(".", 1)
        lst.append((ref, pin))
```

So a net is declared by naming every pin on it:

```python
N("GND",
  "SUPPLY1.GND", "SUPPLY5.GND", ...,
  "J1.2", "J2.4", "U1.GND", "R1.2", "C1.2", "C2.2",
  "U3.GND@1", "U3.GND@40", "U3.EPAD", ...
  "H1.1", "H2.1", "H3.1", "H4.1", ...)
```

**84 nets, 420 connections.** Note `U3.GND@1` — EAGLE's syntax for one of
several same-named pins on a symbol.

### The GPIO table

```python
GPIO_TABLE: list[Gpio] = [
    Gpio("IO0", "27", "BOOT strap / boot button", "ESP_IO0", "IO", True, "-", "-",
         "SW3, R8, J5.6",
         "Weak internal pull-up. Held low at reset = download mode."),
    Gpio("IO1", "39", "ECG analog output", "ECG_OUT", "ANALOG IN", False,
         "ADC1_CH0", "ADC1", "U7 via R30/C22",
         "ADC1 is the only ADC usable while the radio is on."),
    ...
]
```

Fields: module pin, physical pad, function, net, direction, **boot-critical**,
ADC channel, peripheral, what it connects to, and notes. This table is what
`GPIO_ASSIGNMENT.md` is generated from, **and** it is what ERC rule R9 checks
the design against — so a GPIO used in a net but missing from this table is an
ERC error, not a documentation gap.

## 6.4 — The floorplan resolver

The per-part board coordinates in `PARTS` were laid out for an earlier, smaller
outline. Rather than restating 150 coordinates, `design.py` translates each
schematic sheet **as a block**:

```python
SHEET_OFFSET = {
    1: (3.0,  3.0),    # Z1 power / charging
    2: (2.0, 10.0),    # Z2 ESP32 core
    3: (6.0,  5.0),    # Z4 I2C sensors
    4: (13.0, 3.0),    # Z3 ECG analog
    5: (6.0,  3.0),    # Z5 mechanical sensing
    6: (13.0, 10.0),   # Z6 alerts
    7: (6.0, 10.0),    # Z7 user input / storage
}
```

Every part keeps its position **relative to the pin it serves** — a decoupling
capacitor stays next to its IC. Then parts whose position is a *mechanical*
decision are pinned explicitly:

```python
EDGE_PLACEMENT = {
    # bottom edge: every sensor / power lead leaves here
    "J2":  (12.0, 3.0, "R0"),      # USB / 5 V charge input
    "J4":  (25.0, 3.0, "R0"),      # fuel-gauge breakout
    "J8":  (38.0, 3.0, "R0"),      # load cell (JST-PH-4)
    "J15": (48.5, 3.0, "R0"),      # hall / limit switch
    "J14": (56.0, 3.0, "R0"),      # piezo
    # FSR + stretch: vertical headers so they do not wall off the board
    "J9":  (35.5, 10.0, "R90"),
    "J10": (35.5, 16.0, "R90"),
    "J11": (35.5, 22.0, "R90"),
    "J12": (35.5, 28.0, "R90"),
    "J13": (61.0, 10.0, "R90"),
    # left edge
    "J5":  (2.3, 30.0, "R90"),     # UART programming header
    "J1":  (2.3, 51.0, "R90"),     # Li-Po battery
    "J3":  (2.3, 12.0, "R90"),     # external on/off switch
    # right edge
    "J7":  (97.2, 21.0, "R90"),    # ECG electrodes
    "J17": (97.2, 57.5, "R90"),    # buzzer
    # top edge
    "J16": (86.0, 67.0, "R180"),   # vibration motor
    "J18": (46.0, 67.0, "R0"),     # microSD SPI module
    "J6":  (63.0, 40.0, "R90"),    # optional second AS5600
}
```

> **Why the FSR headers are vertical and inboard.** A long horizontal row of
> through-hole pads across the board is **a wall through both signal layers**.
> Four vertical 1×2 headers in a column cost far less routing area. That is
> also why manufacturing check item 10 reports 6 interior connectors — all six
> take a flying lead from a belt-mounted transducer, so none of them needs a
> board edge.

Then `resolve_placement()` runs a collision resolver that enforces
`COURTYARD_GAP = 0.90 mm` between every pair of courtyards and respects
`ANTENNA_KEEPOUT`, the escape channels and the fan-out keep-outs. This exists
because the tenth defect found in review was **"placement collisions from
hand-picked coordinates"** — 150 coordinates chosen by hand will always collide
somewhere.

`clearance_exceptions()` returns the four fine-pitch rectangles (derived from
`FANOUT_ENVELOPE`) that `validate_drc.py` uses to apply the 0.127 mm rule
**by region**.

## 6.5 — `lib_defs.py` — the component library definition

1 178 lines. **23 packages, 28 symbols, 30 devicesets.**

### The three vendor-drawing footprints

These were **not** IPC-generated. They come from the manufacturer's own
recommended land-pattern drawing, because a vendor drawing beats a generic
calculation every time:

| Function | Package | Key verified detail |
|---|---|---|
| `_esp32_s3_wroom1()` | ESP32-S3-WROOM-1 | **Y_PIN1 = BODY_Y/2 − 7.49** — the pin-1 datum is 7.49 mm below the antenna edge, from Espressif Fig. 11-1. Getting this datum wrong shifts all 40 pads. |
| `_lfcsp20()` | AD8232 LFCSP-20, 4 × 4 mm, 0.5 mm pitch | with the 2.50 mm exposed pad |
| `_wson6()` | TMP117 WSON-6 (TI DRV0006B) | with the thermal pad |
| `_lga14()` | LSM6DSOX LGA-14L, 2.5 × 3.0 mm | `PAD_L, PAD_W = 0.45, 0.25` — **1:1 with the package pad, no IPC enlargement.** Enlargement closed the corner pairs to 0.11 mm; that was defect #7. |

### `THERMAL_VIAS`

Defines the plated vias that stitch each exposed pad to the ground plane —
**9 for the ESP32 module's EPAD**, plus the AD8232 and TMP117 thermal pads.

> 🔵 **These are board-level vias, not package holes.** EAGLE's `<hole>`
> element inside a package is an **UNPLATED** mechanical hole. Drilling an
> unplated hole through a thermal land conducts no heat and breaks the pad.
> That was defect #1, and it is exactly the kind of thing that looks fine in a
> library editor.

### `PACKAGE_HEIGHT`

Every package's height, **labelled by source** — `"datasheet"` or
`"typical"`. This drives both `pcb_3d.png` and the mechanical envelope table in
`MANUFACTURING_CHECK.md`.

Tallest part: **8.50 mm** — the 2.54 mm headers, mated with a crimp housing.
Minimum internal enclosure height therefore about **11.6 mm** including the
substrate and a little clearance.

## 6.6 — `eagle_common.py` — the EAGLE XML layer

592 lines. This is the file that knows about **EAGLE**, as opposed to knowing
about *this board*.

### The layer table

The standard EAGLE layer numbers, **plus two additions** needed for a 4-layer
board:

```python
(2,  "Route2"),      # inner GND plane
(15, "Route15"),     # inner 3V3 plane
```

### The XML emitters

Functions that write `<smd>`, `<pad>`, `<wire>`, `<polygon>`, `<via>`,
`<text>`, `<hole>`, `<package>`, `<symbol>`, `<deviceset>`, `<element>`,
`<signal>` and the `<designrules>` block.

### The IPC-7351B land-pattern generators

Generic packages (0805, SOT-23, SOIC, SOP, SOD-123, headers, JST-PH) are
generated to **IPC-7351B Nominal (Level B)** from verified body dimensions.

### 🔴 The `sot23_package()` fix, preserved as a comment

This is the single most important comment in the codebase:

```python
# The pads sit on the top and bottom edges, so the RADIAL direction is Y
# and the TANGENTIAL direction is X. ... Getting these the wrong way
# round makes 1.10 mm pads on a 0.95 mm pitch overlap - a short between
# adjacent pins that looks perfectly plausible in the library editor.
dx, dy = pad_w, pad_l
```

**That was defect #6, and the part it affected was `U2`, the 3.3 V LDO.** A
VIN-to-GND short on the regulator would have destroyed every board in the first
batch, and it would have been invisible on screen.

## 6.7 — `geom.py`

103 lines. Pin and pad geometry, and coordinate transforms — rotating a pad set
by R0/R90/R180/R270, computing courtyards, mapping symbol pins to package pads.
Small, boring, and used by everything.

---

# PART 7 — Every script, explained

Fourteen files. Roughly 6 400 lines of Python. Here is what each one does, in
the order the build runs them.
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

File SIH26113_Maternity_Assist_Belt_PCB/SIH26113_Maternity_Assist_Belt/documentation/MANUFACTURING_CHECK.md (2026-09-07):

<!-- GENERATED by scripts/gen_reports.py from scripts/design.py plus the router and DRC output. Do not edit by hand: re-run the script. -->

# MANUFACTURING CHECK - SIH26113 Maternity Assist Belt

Every item the brief asks to check before declaring the design complete, with the value the files actually contain. Measured figures come from `validate_drc.py` re-reading the emitted `.brd`; assumptions are labelled as such.

> **No fabricator capability is assumed as verified.** The numbers below are what the board *requires*. Item 7 is the one that has to be checked against a specific fab's quoted capability before ordering - see `REQUIRES_CONFIRMATION.md` H6.

| # | Item | Value | Status |
|---|---|---|---|
| 1 | PCB dimensions | **100 x 70 mm** (70 cm2) | set in `design.py`, outline on layer 20 |
| 2 | Board thickness | **1.6 mm** FR-4 | **assumption** - standard; dielectric split 0.36 / 0.71 / 0.36 mm declared in the rule set |
| 3 | Layer count | **4** - `(1*2*15*16)`; L2 = GND plane, L15 = 3V3 plane | verified in the `.brd` design rules |
| 4 | Copper thickness | **1 oz (35 um)** outer and inner | **assumption** - drives the trace-width calculation in `POWER_BUDGET.md` |
| 5 | Via sizes | drill **0.3 mm**, pad 0.55-0.60 mm | 486 vias, all through (`extent 1-16`) |
| 6 | Minimum trace width | **0.15 mm** (fine-pitch escapes); 0.15, 0.2, 0.25, 0.3, 0.5 mm in use | measured from the emitted tracks |
| 7 | Minimum clearance | **0.130 mm measured anywhere on the board** | 0.15 mm general rule; 0.127 mm inside the 4 declared fine-pitch fan-outs. **Needs a fab quoting 5 mil / 0.127 mm** |
| 8 | Drill sizes | vias 0.3 mm; plated pads 0.8, 1, 2.2 mm | JST PH 0.8 mm is within JST's ø0.7 +0.1 spec; M2 holes 2.2 mm |
| 9 | Component courtyard | **no overlaps**, 0.9 mm minimum gap between courtyards | DRC rule D2, enforced by the placement pass |
| 10 | Connector accessibility | 12 of 18 connectors are on a board edge; see the table below | the 6 interior ones all take a flying lead from an off-board transducer |
| 11 | Antenna keep-out | **20 x 6.6 mm** at the top edge, flush | no pad, via or track inside it (DRC rule D3); both plane polygons are drawn as an L that omits it |
| 12 | Mounting holes | **4 x M2**, 2.2 mm drill, 4.4 mm plated annulus on GND | `H3` is at (2.6, 42) not the top-left corner, because that corner is inside the antenna keep-out |
| 13 | Assembly feasibility | see the assembly table below | **3 parts need a stencil and reflow / hot air**; everything else is hand-solderable |
| 14 | Component availability | **NOT VERIFIED** | distributor stock could not be checked from this environment. `BOM.csv` carries empty Supplier / Supplier PN / Lifecycle columns rather than invented ones |
| 15 | Polarity markings | diodes and LEDs carry a silkscreen cathode bar; pad 1 = cathode on every 2-pin polarised footprint | in the library |
| 16 | Pin 1 markings | silkscreen dot or chamfer on every multi-pin part; **pad 1 is square** on every through-hole connector | in the library |
| 17 | Silkscreen readability | reference designators at 0.8-1.1 mm vector text | **assumption** - most fabs hold 0.8 mm with a 0.15 mm stroke; confirm, see `REQUIRES_CONFIRMATION.md` L3 |
| 18 | Solder-paste / stencil | **required** | order the stencil with the boards - see item 13 |
| 19 | Manufacturing outputs | **NOT GENERATED** | Gerbers and drill files need Fusion's CAM processor; build guide step 19 |

## Connector accessibility (item 10)

| Edge | Connectors |
|---|---|
| bottom (y < 6 mm) | J14, J15, J2, J4, J8 |
| left (x < 6 mm) | J1, J3, J5 |
| right (x > 94 mm) | J17, J7 |
| top (y > 64 mm) | J16, J18 |
| interior | J10, J11, J12, J13, J6, J9 |

The interior connectors are the four FSR headers (`J9`-`J12`), the stretch-sensor header (`J13`) and the optional second AS5600 (`J6`). All six take a flying lead from a transducer mounted on the belt, so none of them needs a board edge - and putting the FSR headers in a vertical row inboard, rather than a long horizontal row along the edge, was deliberate: a row of through-hole pads across the board is a wall through both signal layers. See `DESIGN_ASSUMPTIONS.md` 14.

## Assembly feasibility (item 13)

| Method | Placements |
|---|---|
| hand-solderable | 146 |
| reflow / hot air only | 3 |
| reflow or hot air (castellated) | 1 |

The three parts that cannot be soldered with an iron are the **AD8232** (0.5 mm-pitch QFN with a 2.50 mm exposed pad), the **LSM6DSOX** (0.5 mm LGA) and the **TMP117** (0.65 mm WSON with a thermal pad).

## Mechanical envelope

No STEP geometry is attached to these footprints, so there is no solid model and **no 3D interference check has been done**. What exists instead is a height table (`PACKAGE_HEIGHT` in `lib_defs.py`) and an isometric extrusion of it in `renders/pcb_3d.png` - enough to size an enclosure and spot a connector that will foul a lid, not enough to certify clearance.

| Height | Ref | Package | Height source |
|---|---|---|---|
| **8.50 mm** | J9 | `HDR-1X2` | typical (2.54 mm header, mated with a crimp housing) |
| **8.50 mm** | J7 | `HDR-1X3` | typical (2.54 mm header, mated with a crimp housing) |
| **8.50 mm** | J6 | `HDR-1X5` | typical (2.54 mm header, mated with a crimp housing) |
| **8.50 mm** | J5 | `HDR-1X6` | typical (2.54 mm header, mated with a crimp housing) |
| **8.50 mm** | J2 | `HDR-1X4` | typical (2.54 mm header, mated with a crimp housing) |
| **6.00 mm** | J8 | `JST-PH-4` | typical (JST PH top-entry housing) |
| **6.00 mm** | J1 | `JST-PH-2` | typical (JST PH top-entry housing) |
| **5.00 mm** | SW4 | `TACT-6X6-THT` | typical (6 mm tactile incl. plunger) |
| **3.10 mm** | U3 | `ESP32-S3-WROOM-1` | datasheet (v1.8 Fig. 10-1, 3.1 +/-0.15) |
| **1.75 mm** | U8 | `SOP-16-N` | typical (JEDEC SOIC narrow, 1.75 max) |
| **1.75 mm** | U6 | `SOIC-8-N` | typical (JEDEC SOIC narrow, 1.75 max) |
| **1.45 mm** | U2 | `SOT-23-5` | typical (JEDEC TO-178, 1.45 max) |
| **1.12 mm** | Q2 | `SOT-23-3` | typical (SOT-23, 1.12 max) |
| **1.10 mm** | D8 | `SOD-123` | typical (SOD-123) |
| **0.90 mm** | C8 | `C0805` | typical (0805 MLCC; a 22 uF part can reach 1.4) |
| **0.86 mm** | U5 | `LGA-14L-2.5X3.0` | datasheet (ST DS12814 Fig.28, 0.86 max) |
| **0.80 mm** | D4 | `LED0805` | typical (0805 chip LED) |
| **0.80 mm** | U4 | `WSON-6-DRV0006B` | datasheet (TI DRV0006B, 0.8 max) |
| **0.80 mm** | U7 | `LFCSP-20-4X4-P050` | datasheet (AD8232 Rev.A, 0.80 max) |
| **0.60 mm** | R9 | `R0805` | typical (0805 chip resistor) |

Tallest part: **J9 at 8.5 mm** above the board, so the minimum internal enclosure height is about 11.6 mm including the substrate and a little clearance.

**Keep the battery and any metal at least 10 mm from the antenna region** (top edge, x 9-29 mm). A Li-Po pack laid against it will cost most of the radio range.

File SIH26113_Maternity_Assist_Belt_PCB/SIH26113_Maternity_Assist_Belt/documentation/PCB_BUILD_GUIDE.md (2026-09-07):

# PCB BUILD GUIDE — SIH26113 Maternity Assist Belt

How to open these files in Autodesk Fusion (Electronics), check them, finish
the last few connections and get boards made.

Written for someone who has used a PCB tool once or twice. If you have never
opened an EDA tool at all, work through steps 1–7 first and stop — that is
enough to confirm the design is sound before you commit to anything.

**Before you start, read `REQUIRES_CONFIRMATION.md`.** Three items there are
marked BLOCKING; one of them is a fire risk.

---

## What you already have, and what is left

| | State |
|---|---|
| Component library (`.lbr`) | Complete. 23 footprints, 28 symbols, 30 devices, all pinouts verified against datasheets |
| Schematic (`.sch`) | Complete. 7 sheets, 167 parts, 84 nets, every pin connected |
| Board (`.brd`) | Placed and routed. 4 layers, both planes poured, exposed pads via-stitched. The exact routed / airwire count is in `DRC_REPORT.md` - it is generated from the router's own output, not asserted here |
| **Left to do** | Finish a handful of airwires (step 13), run Fusion's own ERC and DRC (steps 6 and 15), generate manufacturing files (step 19) |

The exact number of remaining airwires is in `DRC_REPORT.md`, and Fusion will
show them the moment you open the board.

---

## STEP 1 — Install and open Autodesk Fusion

**Do:** install Fusion (the free personal-use licence includes Electronics).
Open it, then `File ▸ New Electronics Design`.

**Check:** the Electronics workspace opens with `Schematic` and `PCB` tabs.

**What goes wrong:** older standalone EAGLE 7.x cannot read these files — they
use the EAGLE 9 XML format. EAGLE 9.x, Fusion Electronics, and any current
Fusion all read them. If Fusion offers "Migrate EAGLE project", say yes.

---

## STEP 2 — Import the library

**Do:** in Fusion, `Library ▸ Open Library Manager ▸ Import ▸`
`libraries/SIH26113_Maternity_Assist_Belt.lbr`, and mark it **In Use**.

Or, in EAGLE 9.x, drop the `.lbr` into your `lbr/` folder and enable it in the
Control Panel.

**Check:** the library appears with 30 devices.

**What goes wrong:** if the schematic later shows "device not found", the
library was not marked In Use. The `.sch` and `.brd` also carry a full
embedded copy of the library, so they open correctly even without this step —
importing it separately is only needed if you want to place *new* parts.

---

## STEP 3 — Verify the library symbols and footprints

Do not skip this. It is where a wrong pin number is cheapest to find.

**Do:** open the library and spot-check the four parts where a mistake would
be expensive:

| Device | Check | Against |
|---|---|---|
| `ESP32-S3-WROOM-1` | 41 pads. Pin 1 is the square pad at the antenna end, 7.49 mm below the module's top edge. Pads 1.5 × 0.9 mm on a 1.27 mm pitch, columns 17.5 mm apart | Espressif datasheet v1.8, Fig. 11-1 |
| `AD8232` | 20 pads + `EP`. Pin 1 = `HPDRIVE`, pin 17 = `+VS`, pin 20 = `HPSENSE`. Numbering runs counter-clockwise from top-left | AD8232 Rev. A, Table 3 |
| `LSM6DSOX` | 14 pads. **Pin 1 is at the top-RIGHT** — the datasheet shows a bottom view, and a footprint is drawn top-down, so it is mirrored | LSM6DSOX DS12814 Rev. 4, Fig. 4 |
| `TMP117` | 6 pads + thermal pad 7. Lands 0.45 × 0.30 mm, rows 1.95 mm apart | TMP117 SNOSD82D, p. 41 |

**Check:** in the library editor, hover a pad — the tooltip gives its name.
Compare against the datasheet page cited in `COMPONENT_VERIFICATION.md`.

**What goes wrong:** the LSM6DSOX mirror is the classic error. If pin 1 ends
up top-left instead of top-right, the part is soldered on backwards and
nothing on the I²C bus responds.

---

## STEP 4 — Open the schematic

> **Open it from `fusion_project/`, not from `schematic/`.** EAGLE and Fusion
> pair a schematic with a board **by filename and directory** - opening
> `foo.brd` makes the tool look for `foo.sch` beside it, and no link is stored
> inside either file. This project keeps them in `schematic/` and `pcb/`, so
> opening either from its own folder loads it *standalone*: the
> schematic/board consistency check cannot run and forward annotation is off.
> `python scripts/make_fusion_project.py` (the last step of `build_all.py`)
> gathers the `.lbr`, `.sch` and `.brd` into **`fusion_project/`** with a
> shared base name. Open that.

**Do:** `File ▸ Open ▸ fusion_project/SIH26113_Maternity_Assist_Belt.sch`.

**Check:**

* seven sheets in the sheet list, titled POWER / ESP32-S3 CORE / I2C SENSORS /
  ECG ANALOG / MECHANICAL SENSING / ALERTS / USER INPUT;
* every part shows a reference designator and a value;
* every pin has a short stub with a green net label on it.

**Why it looks like that.** Connections are made by **named net labels on
short stubs**, not by long drawn wires. EAGLE merges same-named nets within
and across sheets, so this is a complete netlist — it is how dense production
multi-sheet schematics are usually drawn. To trace a net, click a label and
EAGLE highlights every occurrence.

**What goes wrong:** if you see red "unconnected pin" crosses, the library did
not load. Re-do step 2.

---

## STEP 5 — Confirm footprint assignment

**Do:** `Tools ▸ Statistics`, or click any part and read its Device field.

**Check:** every part has a package (they were emitted with one), and the
count matches `documentation/PROJECT_STATISTICS.md`.

**What goes wrong:** nothing should, here — the generator refuses to emit a
part without a footprint. If a part shows no package, the library version is
mismatched.

---

## STEP 6 — Run Fusion's ERC

**Do:** in the schematic, `Tools ▸ ERC`.

**Check:** compare Fusion's list against `documentation/ERC_REPORT.md`.

An independent ERC has already been run (`scripts/validate_erc.py`, 11 rule
groups, **0 errors**), but **Fusion's own ERC has never been run on these
files — no EAGLE installation existed where they were produced.** This step is
where that gets done.

**What to expect.** Fusion will probably report these, and each is
intentional — the reasoning is in `ERC_REPORT.md`:

| Fusion will say | Why it is fine |
|---|---|
| `LDO_NC` has only one pin | AP2112 pin 4 is documented "No Connection" |
| `IMU_OCS_AUX` connects only to a test point | LSM6DSOX datasheet: leave OCS_Aux electrically unconnected but soldered. An isolated land does exactly that |
| `TMP_ALERT`, `AS_OUT`, `AS_PGO`, `HX_BASE`, `HX_XO` go to test points | All are datasheet "NC when not used" or optional-function pins |
| Possibly: no supply for some net | Each rail has a `SUPPLY-*` symbol per sheet; approve if it names one of `GND`, `3V3`, `VBAT`, `VBUS` |

**Approve** those in Fusion's ERC dialog so they stop reappearing.
**Anything else is a real finding — investigate it, do not approve it.**

---

## STEP 7 — Fix ERC errors

**Do:** for each error Fusion reports that is *not* in the table above, click
it to jump to the location and fix it.

**Check:** re-run ERC until only the approved exceptions remain.

**What goes wrong:** the temptation is to approve everything. Don't. An
approved "output conflict" is two drivers fighting, and it will destroy a pin.

---

## STEP 8 — Open the board

**Do:** with the schematic open, switch to the `PCB` tab, or open
`fusion_project/SIH26113_Maternity_Assist_Belt.brd` directly - again from
`fusion_project/`, so Fusion sees the matching pair (step 4).

**Check:**

* board outline 100 × 70 mm;
* 150 components placed inside it, none overlapping;
* an orange hatched rectangle in the top-left — the antenna keep-out;
* dashed blue rectangles labelled Z1–Z7 — the placement zones (documentation
  only, layer 48);
* some yellow airwires. Those are the unrouted connections; step 13 deals with
  them.

**Do this immediately:** `Tools ▸ Ratsnest` (or type `RATSNEST`). Nothing looks
right until you do — this is what makes Fusion compute the copper pours.

**What goes wrong:** if the board opens with *every* connection as an airwire,
the schematic and board have lost their link. Close both, open the `.sch`
first, then switch to the PCB tab.

---

## STEP 9 — Verify the board outline and stack-up

**Do:** check the outline on layer 20 (Dimension), then `Tools ▸ DRC ▸ Layers`
and confirm the setup is `(1*2*15*16)`.

**Check:**

| Layer | Should contain |
|---|---|
| 1 `Top` | tracks, all pads, all components |
| 2 `Route2` | one big **GND** polygon |
| 15 `Route15` | one big **3V3** polygon |
| 16 `Bottom` | tracks only, no components |

Both plane polygons are drawn as an **L** that omits the top-left corner. That
is intentional: Espressif require no copper — planes included — beneath the
module antenna, and an EAGLE polygon cannot carry a hole.

**What goes wrong:** if Fusion reports a 2-layer setup, the design rules did
not load. `Tools ▸ DRC ▸ Load` and pick the rules embedded in the board, or set
layer setup to `(1*2*15*16)` by hand.

---

## STEP 10 — Review the placement

Placement is done, but it is worth understanding before you move anything.

**Do:** look at each zone and read it against `renders/pcb_assembly.png`.

| Zone | Where | Contents |
|---|---|---|
| Z1 | bottom-left | charger `U1`, LDO `U2`, battery `J1`, USB/5 V `J2`, fuel-gauge header `J4` |
| Z2 | left, top | ESP32-S3 module `U3`, decoupling in the strip to its left, UART header `J5` |
| Z5 | bottom-centre | HX711 `U8`, load cell `J8`, FSR headers `J9`–`J12`, piezo and hall conditioning |
| Z4 | centre | TMP117 `U4`, LSM6DSOX `U5`, AS5600 `U6`, both I²C pull-up pairs |
| Z7 | top-centre | SOS `SW4`, RESET `SW2`, BOOT `SW3`, microSD header `J18`, status LEDs |
| Z3 | right, bottom | **AD8232 `U7` and its 25 passives** — the whole ECG chain |
| Z6 | right, top | motor FET `Q1`, buzzer FET `Q2`, their connectors |

**Three placement rules you must not break if you rearrange anything:**

1. **The module antenna stays flush with the top board edge**, with no copper
   beneath it. Moving `U3` down into the board detunes the radio.
2. **Nothing goes in the escape channels** — the reserved bands either side of
   and below the module's pad rows. 36 signals leave a 1.27 mm pitch through
   them; fill a channel and the board becomes unroutable.
3. **Keep ECG away from the motor driver and the antenna.** `U7` is in the
   opposite corner from both for a reason.

**Check:** run `scripts/validate_drc.py` after any change — rule D2 finds
courtyard overlaps that are easy to create and hard to see.

---

## STEP 11 — Route the critical analog signals

Already done, but check the result rather than trusting it.

**Do:** in Fusion, hide every layer except 1, 2 and 17. Look at the ECG block.

**Check:**

* the electrode signals from `J7` reach `R18`/`R19` in a few millimetres —
  that is the unprotected high-impedance part of the path and it must be
  short;
* `R18`/`R19` are positioned symmetrically with respect to `+IN` and `−IN`.
  The datasheet asks for length-matched, symmetric input traces to hold CMRR;
* the high-impedance nodes — `ECG_HPSENSE`, `ECG_IAOUT`, `ECG_SW`,
  `ECG_REFIN`, `ECG_REFOUT` — are short. These are 10 MΩ nodes; every extra
  millimetre picks up noise;
* ECG tracks are on **layer 1**, directly above the layer-2 GND plane.
  `DRC_REPORT.md` lists any that had to use layer 16 instead.

**What goes wrong:** if you re-route these, do not put a via in the middle of
a 10 MΩ node — the via's extra surface area is a leakage and pickup path.

---

## STEP 12 — Route power

Already done. `3V3` and `GND` are planes and need no routing at all;
`VBUS`, `VBAT` and the motor path are 0.50 mm tracks.

**Check:**

* trace widths: `VBUS`/`VBAT`/motor at 0.50 mm (≈ 1.45 A at 10 °C rise, 1 oz
  copper, IPC-2221), signals at 0.20 mm (≈ 0.74 A) — see `POWER_BUDGET.md`;
* the motor's current loop is small: `C37` → `J16` → motor → `Q1` → plane;
* every plane-net pad has its own via to its plane. Click a `GND` pad and
  confirm a via sits within about 0.8 mm.

**What goes wrong:** if you widen a power track, re-run DRC. 0.50 mm tracks in
0.9 mm gaps between passives have little room to grow.

---

## STEP 13 — Finish the remaining airwires

**This is the main job left.**

**Do:** `View ▸ Show/Hide layers`, turn on `Unrouted` (layer 19). Each yellow
line is a connection to complete. Use the interactive router (`ROUTE`, or the
Route tool), pick the net-class width Fusion offers, and draw it.

The list is in `DRC_REPORT.md` with the specific terminal that could not be
reached. All of them are at the four most congested spots on the board: the
ESP32 module (36 signals escaping a 1.27 mm pitch), the AD8232 (0.5 mm QFN),
the LSM6DSOX (0.5 mm LGA) and the HX711 (whose 9 plane pads each take a via
beside the pad).

**Practical hints:**

* Every pad already has a **fan-out stub** — a short escape track ending in
  open space. Start from the end of the stub, not from the pad.
* Use the **bottom layer** freely. It is much emptier than the top, and both
  signal layers sit against a plane, so neither is electrically worse.
* Place a via right at the stub end and continue on layer 16. The stubs are
  **staggered** — alternate ones are longer — specifically so each has room
  for its own via.
* Set the grid to 0.05 mm and enable 45° routing. Fusion's default 90° mode
  wastes space.

**Check:** the `Unrouted` layer is empty, and `Tools ▸ DRC` reports no
"Unrouted" items.

**Rough effort:** each remaining net is a short connection with both ends
already fanned out. Half an hour of interactive routing should clear them.

---

## STEP 14 — Verify the ground plane

**Do:** type `RATSNEST` again after any routing change — Fusion recomputes
pours on demand, not automatically.

**Check:**

* layer 2 is a continuous `GND` pour with no large islands cut off by via
  clusters;
* layer 15 is a continuous `3V3` pour;
* both stop short of the antenna keep-out;
* under the ECG block, layer 2 is **unbroken**. This is the single most
  important electrical property of the board.

**What goes wrong:** a dense row of vias can pinch a plane into two regions.
Fusion shows the result after `RATSNEST` — look for a thin neck, and if you
find one under the analog section, move a via.

---

## STEP 15 — Run Fusion's DRC

**Do:** `Tools ▸ DRC`. The board carries its own rule set
(`SIH26113_4layer`):

| Rule | Value |
|---|---|
| Minimum clearance, all combinations | 0.20 mm |
| Minimum track width | 0.15 mm |
| Minimum drill | 0.30 mm |
| Copper to board edge | 0.40 mm |
| Annular ring | 0.25 × drill, 0.15–0.50 mm |

**Check:** compare against `documentation/DRC_REPORT.md`, which lists what the
independent geometric check found.

**Again, plainly: Fusion's DRC has never been run on these files.** No EAGLE
installation existed where they were produced. `scripts/validate_drc.py`
measures real geometry independently — segment-to-segment distances,
segment-to-pad distances, pad bounding boxes, drill sizes, keep-out
containment — but it is not the same program.

**What to expect:** "Unrouted" items until step 13 is finished. Anything else
needs investigating.

---

## STEP 16 — Fix DRC errors

**Do:** work the list. Clearance violations usually mean nudging one track;
"copper near dimension" means a track wandered toward the edge.

**Check:** DRC clean except for anything you have consciously approved.

**What goes wrong:** approving a clearance error because it is "only slightly
under". 0.15 mm instead of 0.20 mm is often fine and often not — it depends on
the fab. Ask them, or fix it.

---

## STEP 17 — Inspect in 3D

**Do:** in Fusion, `PCB ▸ 3D PCB` (or push the board to a 3D document).

**Check:** components sit where you expect; connectors face outward; the
module is at the board edge.

**Limitation, stated plainly:** **no 3D models are attached to these
footprints.** The library carries footprints and 2D package outlines (layer
51, `tDocu`) but no STEP geometry. Fusion will show generic extrusions from
the silkscreen, which is enough to catch a connector facing the wrong way but
**not** enough for a real interference check.

If you need a proper mechanical check, download STEP models — Espressif
publish one for the WROOM-1, and Fusion's own library has SOIC/SOT/0805
models — and attach them per footprint.

---

## STEP 18 — Check mechanical clearances

**Do:** measure against the enclosure design.

**Check:**

| Item | Value |
|---|---|
| Board | 100 × 70 mm, 1.6 mm FR-4 |
| Tallest part | ESP32-S3-WROOM-1 at 3.1 mm, plus THT connector bodies (~6 mm for the 2.54 mm headers with housings) |
| Mounting holes | M2, at (3, 3), (97, 3), **(2.6, 42)** and (97, 67) |
| Antenna | flush with the top edge, x 9–29 mm — **keep 10 mm clear of metal, battery and wiring** |
| Connector faces | bottom edge: sensors and power. Left edge: battery, UART, on/off. Right edge: ECG electrodes, buzzer. Top edge: motor, microSD |
| Buttons | `SW4` SOS at (52, 63.5) needs a plunger through the enclosure |

**Note `H3` is at (2.6, 42), not the top-left corner** — that corner is inside
the antenna keep-out and a plated hole there would detune the radio. See
`REQUIRES_CONFIRMATION.md` L1.

**What goes wrong:** the battery. A Li-Po pack placed against the antenna will
kill the radio range. Keep it below the board or at the opposite end.

---

## STEP 19 — Generate manufacturing outputs

**Do:** `Manufacturing ▸ CAM Processor`, pick a 4-layer Gerber X2 job (or your
fab's own job file), and generate.

**Check** you get:

| File | Content |
|---|---|
| `*.GTL` / `*.GBL` | top and bottom copper |
| `*.G2L` / `*.G15` (or `.GP1`/`.GP2`) | the two inner planes |
| `*.GTS` / `*.GBS` | solder mask |
| `*.GTO` / `*.GBO` | silkscreen |
| `*.GML` / `*.GKO` | board outline |
| `*.TXT` / `*.DRL` | drill file |
| `*.GTP` | top solder paste — **needed for the stencil** |

**You need a stencil.** Three parts cannot be soldered with an iron: the
AD8232 (0.5 mm QFN with a 2.5 mm exposed pad), the LSM6DSOX (0.5 mm LGA) and
the TMP117 (0.65 mm WSON with a thermal pad). Order the stencil with the
boards.

Specify to the fab:

* 4 layers, 1.6 mm FR-4, 1 oz outer copper;
* minimum track **0.15 mm**; minimum gap **0.127 mm (5 mil)** - the
  measured minimum copper clearance anywhere on the board is
  **0.130 mm**, so a 6 mil (0.152 mm) process will not make this board.
  5 mil is a standard but often non-default option - see
  `REQUIRES_CONFIRMATION.md` H6;
* minimum drill **0.30 mm**;
* HASL or ENIG (ENIG is better for the fine-pitch parts);
* stack-up `(1*2*15*16)` — tell them layers 2 and 15 are **planes**.

**No Gerbers are included in this project.** They need EAGLE's CAM processor,
which was not available. `DRC_REPORT.md` records that as NOT GENERATED.

---

## STEP 20 — Final review before you spend money

Go through `documentation/FINAL_REVIEW.md` — it is a second-pass review of
this design against 27 specific failure modes, with the evidence for each.

Then, specifically:

- [ ] `REQUIRES_CONFIRMATION.md`: all three BLOCKING items resolved
- [ ] The Li-Po cell at `J1` **has integrated protection** (B1)
- [ ] `J1` polarity checked with a meter against the actual pigtail (B1)
- [ ] Motor voltage rating checked, `R45` value decided (B3)
- [ ] Module ordered is **`-N8R2`**, not N8R8 or N16R8 (H5)
- [ ] Tactile switch pin grid confirmed as 6.5 × 4.5 mm (H4)
- [ ] `R37` set for the actual stretch sensor, or accepted as a placeholder (H2)
- [ ] Fusion ERC run, exceptions approved and understood (step 6)
- [ ] Fusion DRC clean (step 15)
- [ ] `Unrouted` layer empty (step 13)
- [ ] Gerbers + drill + **paste** generated and viewed in a Gerber viewer
- [ ] Stencil ordered
- [ ] Fab confirmed they can do **0.127 mm (5 mil) gap**, 0.15 mm track and
      0.30 mm drill on 4 layers (H6 - the measured minimum clearance is
      0.130 mm, so a 6 mil default will fail)

---

## Bring-up order, once the boards arrive

Do not populate everything and apply power. In this order:

1. **Power only** — `U1`, `U2`, `R1`–`R6`, `C1`–`C6`, `D1`, `D2`, `J1`, `J2`,
   `J3`. Apply 5 V to `J2`. Measure `TP2` (`3V3`) = 3.3 V ±1.5 %, `TP1`
   (`VBAT`), `TP4` (`VBUS`). Check `D1` lights with a battery connected.
   **Do not proceed until 3V3 is correct** — every other part is on that rail.
2. **Module** — `U3`, `C7`, `C8`, `R7`, `C10`, `SW2`, `SW3`, `R8`, `J5`.
   Connect USB to `J2` and confirm the ESP32-S3 appears as a serial device.
   Flash something trivial. Confirm `D3`/`D4` blink from `IO45`/`IO46`.
3. **I²C sensors** — `U4`, `U5`, `U6` and their passives. Run an I²C scan on
   both busses. Expect **0x48 and 0x6A on the sensor bus**, **0x36 on the
   angle bus**. If a device is missing, check its orientation first — the
   LSM6DSOX is the usual suspect (step 3).
4. **Mechanical sensing** — `U8` and the FSR/stretch/piezo/hall front ends.
   Verify HX711 readings change when you press the load cell.
5. **Alerts** — `Q1`, `Q2` and their networks. Test with short pulses first;
   confirm the FETs are off at boot before connecting the motor.
6. **ECG last.** Populate `U7` and its 25 passives. Before touching a person:
   check `TP11` (`ECG_REFOUT`) sits at ~1.65 V, wait 2.5 s after power-up for
   the reference to settle, then look at `TP10` (`ECG_OUT`) on a scope —
   it should also idle near 1.65 V. Only then attach electrodes, **on battery
   power with USB disconnected** (`REQUIRES_CONFIRMATION.md` B2).

---

## Regenerating everything from source

The whole project is generated from `scripts/design.py`. To change something,
edit that and re-run:

```bash
python scripts/generate_library.py    # .lbr, with a model self-check
python scripts/validate_erc.py        # ERC (must pass before continuing)
python scripts/generate_schematic.py  # .sch, cross-checked against the model
python scripts/generate_board.py      # place, route, emit .brd
python scripts/validate_drc.py        # DRC on the emitted geometry
python scripts/render.py              # PNG renders of the real files
python scripts/generate_docs.py       # netlist, GPIO table, BOM, reports
```

Or all of it: `python scripts/build_all.py`

The generators cross-check themselves. `generate_schematic.py` re-parses its
own output and asserts the netlist matches the model exactly;
`generate_board.py` does the same for elements and signals. If the model and
the files ever disagree, the build fails rather than emitting something wrong.

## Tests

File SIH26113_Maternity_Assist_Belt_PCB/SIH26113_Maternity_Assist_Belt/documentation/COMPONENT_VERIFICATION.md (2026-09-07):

# COMPONENT VERIFICATION — SIH26113 Maternity Assist Belt

Every symbol pinout and every footprint dimension in
`libraries/SIH26113_Maternity_Assist_Belt.lbr` traces back to one of the rows
below. Where a datasheet could not be retrieved, that is stated rather than
papered over.

## Verification levels

| Level | Meaning |
|---|---|
| **V** | Taken from the manufacturer's own datasheet / package-outline / recommended-land-pattern drawing. The document was downloaded and read while producing this design. |
| **I** | Land pattern computed from **IPC-7351B** Nominal (Level B) density, using body and terminal dimensions that are themselves level V. |
| **S** | De-facto standard geometry (2.54 mm pin header, M2 hole, 6 mm tactile switch). Widely interchangeable, but the exact vendor part should still be confirmed. |
| **U** | **Unverified.** Datasheet not retrievable. Not placed on the board. |

## How the datasheets were read

`analog.com`, `mouser.com` and `jst.co.jp` were unreachable or bot-blocked
from this network. Working method:

1. Download the PDF, falling back to manufacturer-authored copies hosted
   elsewhere (`documentation.espressif.com`, `ti.com`, `st.com`,
   `diodes.com`, `jst-mfg.com`, `cdn.sparkfun.com`).
2. Extract text with `pypdf` and read the pin-function and package tables.
3. Where a mechanical drawing is vector-only and its dimensions do not
   extract as text, render the page to a bitmap at 5× with PyMuPDF and read
   the dimensions off the drawing.

Step 3 is how two numbers that appear nowhere in the extracted text were
obtained: the **ESP32-S3-WROOM-1 pin-1 datum (7.49 mm below the antenna
edge)** and the **JST PH PCB hole diameter (ø0.7 +0.1/−0 mm)**. Both matter —
the first sets where all 40 module pads land relative to the antenna
keep-out, the second sets whether the battery connector fits.

---

## A. Main ICs

| Component | Manufacturer | Exact part | Package | Supply | Interface | Pinout | Footprint | Source |
|---|---|---|---|---|---|---|---|---|
| Central MCU | Espressif Systems | **ESP32-S3-WROOM-1-N8R2** | 41-pad castellated module, 25.5 × 18 × 3.1 mm | 3.0–3.6 V | Wi-Fi b/g/n, BLE 5, 2 × I²C, SPI, UART, USB-Serial-JTAG, ADC | **V** — datasheet v1.8 Table 3-1, all 41 pins | **V** — v1.8 Fig. 11-1 land pattern + Fig. 10-1 dimensions | *ESP32-S3-WROOM-1 & WROOM-1U Datasheet v1.8*, Espressif |
| ECG analog front end | Analog Devices | **AD8232ACPZ-R7** | 20-lead LFCSP_WQ (CP-20-10), 4 × 4 mm, 0.5 mm pitch, 2.50 mm SQ exposed pad | **2.0–3.5 V only** | analog out to ADC; 3 control in, 2 status out | **V** — Rev. A Table 3, all 20 pins + EP | **I** — body/terminal/EP from the Rev. A outline drawing (JEDEC MO-220-WGGD); lands IPC-7351B Nominal 0.80 × 0.28 mm at 1.75 mm from centre | *AD8232 Data Sheet Rev. A*, Analog Devices |

### The AD8232 supply rail is a hard constraint

Absolute maximum supply is **3.5 V**, and the datasheet's *Power Supply
Regulation and Bypassing* section warns that a lithium cell "may exceed the
absolute maximum ratings of the AD8232" during a charge cycle. On this board
the AD8232 sits on the regulated **3V3** rail and never sees `VBAT` (3.0–4.2 V,
and up to 4.2 V while charging).

The architecture diagram does not say which rail feeds it. Getting this wrong
destroys the part on first charge, so it is called out here and in
`DESIGN_ASSUMPTIONS.md`.

### Verified ESP32-S3-WROOM-1 land pattern

Reproduced in the library exactly as Espressif specify it:

| Parameter | Value | Where it comes from |
|---|---|---|
| Module body | 25.5 × 18.0 × 3.1 mm | Fig. 10-1 |
| Land count | 40 signal + 1 EPAD | Table 3-1 |
| Land size | 1.5 mm radial × 0.9 mm tangential | Fig. 11-1 (`40 × 1.5`, `40 × 0.9`) |
| Pitch | 1.27 mm | Fig. 11-1 |
| Column row spacing | 17.5 mm centre-to-centre | Fig. 11-1 |
| Column pad span | 16.51 mm (14 pads/side) | Fig. 10-1 / 11-1 |
| End-row pad span | 13.97 mm (12 pads), 2.015 mm inset each side | Fig. 11-1 |
| **Pin 1 centre** | **7.49 mm below the antenna-end edge** | Fig. 11-1, read from a 5× render |
| Antenna area | 6.0 mm at the pin-1 end, full width | Fig. 11-1 |
| Numbering | 1–14 left column top→bottom, 15–26 end row left→right, 27–40 right column bottom→top, 41 = EPAD | Table 3-1 |

The EPAD is emitted as one 3.4 mm land inside Espressif's 3 × 3 thermal-copper
envelope, plus nine plated 0.3 mm vias **placed at board level, not in the
package**. EAGLE's `<hole>` element is an *unplated* mechanical hole; putting
thermal "vias" in a package that way would drill unplated holes through the
ground land, which is a real manufacturing defect. See `THERMAL_VIAS` in
`scripts/lib_defs.py`.

---

## B. Sensor ICs

| Component | Manufacturer | Exact part | Package | Supply | Interface | Pinout | Footprint | Source |
|---|---|---|---|---|---|---|---|---|
| Temperature | Texas Instruments | **TMP117AIDRVR** | 6-pin WSON (DRV0006B), 2.0 × 2.0 mm, 0.65 mm pitch, 1.0 × 1.6 mm thermal pad | 1.7–5.5 V | I²C, addr **0x48** (ADD0→GND) | **V** — SNOSD82D Table 5-1, WSON column | **V** — TI's own *EXAMPLE BOARD LAYOUT*, SNOSD82D p. 41: lands 0.45 × 0.30 mm, rows 1.95 mm apart | *TMP117 SNOSD82D* rev. Sept 2022, TI |
| 6-axis IMU | STMicroelectronics | **LSM6DSOXTR** | LGA-14L, 2.5 × 3.0 × 0.86 mm, 0.5 mm pitch | VDD 1.71–3.6 V, VDDIO 1.62–3.6 V | I²C, addr **0x6A** (SA0→GND) | **V** — DS12814 Rev. 4 Table 1, all 14 pins | **I** — geometry from DS12814 Rev. 4 Fig. 28 (14 pads 0.475 × 0.25 mm, 1.5/1.0 mm row spans); lands enlarged to 0.50 × 0.28 mm per IPC-7351B. *ST's TN0018 land-pattern note was not retrievable.* | *LSM6DSOX DS12814 Rev. 4*, ST |
| Magnetic angle | ams-OSRAM | **AS5600-ASOM** | SOIC-8; D 4.90, E 6.00, E1 3.90, e 1.27 mm | 3.3 V or 5 V mode | I²C, addr **0x36 — fixed, not configurable** | **V** — DS000365 v1-06 Fig. 4, all 8 pins | **I** — outline from DS000365 v1-06; lands IPC-7351B SOIC127P600X175-8N Nominal | *AS5600 DS000365 v1-06*, ams-OSRAM |
| Bridge / load-cell ADC | Avia Semiconductor | **HX711** | SOP-16L, body 9.90 × 3.90 mm, lead span 6.00 mm, e 1.27 mm | 2.6–5.5 V | 2-wire serial (DOUT + PD_SCK) | **V** — HX711 English datasheet Table 1, all 16 pins | **I** — *Package Dimensions* page of the same datasheet; lands IPC-7351B SOIC127P600X175-16N Nominal | *HX711 datasheet*, Avia Semiconductor |
| Battery fuel gauge | Analog Devices (Maxim) | MAX17048 | WLP-8 (0.9 × 1.7 mm) or TDFN-8 (2 × 2 mm) | 2.5–4.5 V | I²C, addr **0x36 — fixed** | **U — NOT VERIFIED** | **U — NOT VERIFIED, NOT PLACED** | analog.com and every distributor mirror tried were unreachable or bot-blocked |

### Why the MAX17048 is not on the board

Its datasheet could not be retrieved, so neither its pin assignment nor its
land pattern could be checked against primary documentation. Both packages
are also awkward for a hackathon prototype — a 0.9 × 1.7 mm 8-bump WLP is not
hand-assemblable at all.

Rather than invent a footprint, the design does two things:

* **`J4`** — a 5-way 2.54 mm header (`VBAT`, `GND`, `3V3`, `SDA`, `SCL`) for
  an off-the-shelf MAX17048 breakout. Header geometry is standard, so nothing
  is guessed.
* **`R5`/`R6`/`C6`** — a 470 k/470 k divider from `VBAT` to `IO9`
  (ADC1_CH8), giving a battery-voltage reading that works whether or not the
  gauge is fitted. 4.2 V at the cell reads 2.10 V at the pin, comfortably
  inside ADC1's range.

Recorded as an architectural change in `DESIGN_ASSUMPTIONS.md` and as an open
item in `REQUIRES_CONFIRMATION.md`.

---

## C. Power components

| Component | Manufacturer | Exact part | Package | Rating | Pinout | Footprint | Source |
|---|---|---|---|---|---|---|---|
| Li-ion charger | NanJing Top Power ASIC | **TP4056-42-SOP8-PP** | SOP-8 | 4.2 V float ±1.5 %, up to 1 A, programmable | **V** — TP4056 datasheet p. 2, every pin described individually | **I** — SOP-8 per the datasheet's own package/order table; lands IPC-7351B SOIC127P600X175-8N Nominal | *TP4056 datasheet*, NanJing Top Power |
| 3V3 regulator | Diodes Incorporated | **AP2112K-3.3TRG1** | SOT-25 (SOT-23-5) | 600 mA min, 250 mV dropout @ 600 mA, ±1.5 % | **V** — AP2112 DS39724 Rev. 2-2 *Pin Descriptions*, SOT25 column | **I** — JEDEC TO-178; lands IPC-7351B SOT95P280X145-5N Nominal | *AP2112 DS39724 Rev. 2-2*, Diodes |

### TP4056 pins as used

| Pin | Name | This design |
|---|---|---|
| 1 | TEMP | **tied to GND.** The datasheet: "The temperature sense function can be disabled by grounding the TEMP pin." No pack NTC is assumed. |
| 2 | PROG | `R1` = 2.4 kΩ → GND. The datasheet's characteristics table gives **R_PROG = 2.4 k → 500 mA**. 500 mA rather than 1 A halves the linear charger's dissipation, which matters because this SOP-8 footprint carries no thermal land. |
| 3 | GND | plane |
| 4 | VCC | `VBUS` (5 V in) |
| 5 | BAT | `VBAT` — cell positive and system rail |
| 6 | STDBY | open drain → green LED `D2` |
| 7 | CHRG | open drain → red LED `D1` |
| 8 | CE | tied to VCC — enabled whenever 5 V is present |

> **Known limitation, stated because it is real.** The TP4056 has no
> power-path switching. The system load hangs off the same `BAT` node as the
> cell, so load current flows through the charger and disturbs its C/10
> termination detection. This is how essentially every TP4056 prototype is
> wired and it does work, but a production build should use a power-path
> charger (MCP73871, BQ24075 or similar).

---

## D. Discrete semiconductors

| Component | Part | Package | Rating | Pinout | Footprint | Note |
|---|---|---|---|---|---|---|
| Motor / buzzer low-side switch | **AO3400A** (Alpha & Omega), or any pin-compatible logic-level N-FET | SOT-23-3 | 30 V, 5.7 A, V_GS(th) ≤ 1.4 V, R_DS(on) 34 mΩ @ 4.5 V | **S** — 1 = Gate, 2 = Source, 3 = Drain, the universal SOT-23 N-MOSFET assignment | **I** — IPC-7351B SOT95P237X112-3N Nominal | Gate threshold must suit 3.3 V drive — confirm on any substitute |
| Flyback / clamp | **1N5819HW** | SOD-123 | 40 V, 1 A Schottky | 2-pin, pad 1 = cathode (band) | **I** — IPC-7351B DIOM2616X110N Nominal | D5–D8 |
| Indicator LEDs | generic | 0805 | — | pad 1 = cathode | **I** — IPC-7351B | D1–D4 |

---

## E. Passives

| Type | Package | Footprint | Values used |
|---|---|---|---|
| Resistors | 0805 (2012 metric) | **I** — IPC-7351B RESC2012X65N Nominal: lands 1.15 × 1.40 mm, 0.75 mm inner gap | 0R, 100R, 1k, 2k4, 4k7, 10k, 100k, 330k, 470k, 1M, 10M |
| Capacitors | 0805 (2012 metric) | **I** — IPC-7351B CAPC2012X135N Nominal | 1n, 3n9, 8n2, 10n, 100n, 220n, 1u, 10u, 22u |

Voltage ratings: 16 V X7R/X5R is fine on `3V3`; use ≥ 16 V on `VBAT`/`VBUS`;
**`C34` (piezo AC coupling) must be ≥ 50 V**, because a piezo film's
open-circuit transient reaches tens of volts. That requirement is carried in
the BOM value string as `100n/50V` so it cannot be lost.

---

## F. Connectors and electromechanical

| Component | Part | Footprint | Source |
|---|---|---|---|
| Li-Po battery (`J1`), load cell (`J8`) | **JST PH series** — S2B-PH-K-S / S4B-PH-K-S | **V** — JST ePH catalogue, *PC board layout and Assembly layout (Through-hole type)*: pitch 2.00 ±0.05 mm, **PCB hole ø0.7 +0.1/−0 mm**, outline offsets (1.95) × (1.7) mm. Drill specified 0.8 mm — inside JST's tolerance and following their Note 3, "when using PCB made of hard fibreglass material, please consider a larger hole diameter". | `jst-mfg.com/product/pdf/eng/ePH.pdf`, dimensions read from a 5× render because the PDF's fonts do not extract as text |
| All 2.54 mm headers (`J2`–`J7`, `J9`–`J18`) | generic 1×N | **S** — 2.54 mm pitch, 1.0 mm drill, 1.8 mm pad, suiting the 0.64 mm square posts every common header uses. Pad 1 square. | de-facto standard |
| Push-buttons `SW2` RESET, `SW3` BOOT, `SW4` SOS | 6 × 6 mm THT tactile, TL1105 / B3F-10xx family | **S** — 4 leads on a 6.5 × 4.5 mm grid, 1.0 mm drill. Leads 1–2 and 3–4 internally common, mapped with an EAGLE multi-pad connect (`pad="1 2"`). | de-facto standard — **confirm against the chosen vendor part** |
| Mounting holes `H1`–`H4` | M2 | **S** — 2.2 mm drill, 4.4 mm plated annulus tied to GND, 4.6 mm keep-out ring | — |
| Test points `TP1`–`TP19` | — | 1.5 mm round SMD land | — |

---

## G. Off-board transducers

These sit on flying leads; the board carries only their connector and signal
conditioning. **None of their electrical characteristics were verified**,
because no specific part has been selected.

| Function | Connector | On-board conditioning | Status |
|---|---|---|---|
| Belt pressure ×4 | `J9`–`J12` | 10 kΩ divider + 10 nF filter → ADC1 | FSR402 assumed for divider sizing — see `DESIGN_ASSUMPTIONS.md` |
| Load cell | `J8` (JST-PH-4) | HX711 channel A, gain 128, ratiometric to AVDD | bridge resistance and sensitivity **TBD** |
| Abdominal stretch | `J13` | divider + 10 nF filter → ADC1 | **resistance range unknown — `R37` = 10 k is a placeholder** |
| Fetal movement (piezo film) | `J14` | 10 MΩ load, 100 nF/50 V AC coupling, mid-rail bias, 100 kΩ series, Schottky clamps to 3V3 and GND | film capacitance **TBD** |
| Hall / limit switch | `J15` | 10 kΩ pull-up + 100 nF debounce | open-collector or mechanical assumed |
| Vibration motor | `J16` | N-FET low side, flyback diode, optional series ballast `R45` | **voltage / current rating TBD** |
| Buzzer | `J17` | N-FET low side from 3V3, flyback diode | magnetic (inductive) assumed |
| ECG electrodes ×3 | `J7` | 330 kΩ series protection per lead, 10 MΩ bias, driven RLD electrode | standard Ag/AgCl assumed |

---

## Summary

| | Count |
|---|---|
| Placed ICs/modules with a **fully verified** pinout (V) | **8 of 8** |
| Footprints from a **manufacturer land-pattern drawing** (V) | 3 — ESP32-S3-WROOM-1, TMP117 WSON, JST PH |
| Footprints **IPC-7351B-derived** from verified body dimensions (I) | 8 |
| Footprint families on **de-facto standard** geometry (S) | 4 |
| Components **not verified and therefore not placed** (U) | 2 — MAX17048, FS8205A |

No pin mapping in this library was written from memory or inferred from the
architecture diagram.

---

## H. Parts verified but deliberately NOT placed

These were researched after the first pass. Their data is recorded here so the
decision to place them is informed rather than blocked.

### DW01A — one-cell Li-ion/polymer battery protection controller ✅ V

*Primary source: **DW01A Rev. 1.0, DW01A-DS-10_EN, JUN 2009** (FSC), §6 "Pin
Configuration and Package Marking Information".* Package **SOT-23-6**.

| Pin | Symbol | Description (datasheet wording) |
|---|---|---|
| 1 | `OD` | MOSFET gate connection pin for discharge control |
| 2 | `CS` | Input pin for current sense, charger detect |
| 3 | `OC` | MOSFET gate connection pin for charge control |
| 4 | `TD` | Test pin for reduce delay time |
| 5 | `VCC` | Power supply, through a resistor (R1) |
| 6 | `GND` | Ground pin |

Thresholds (§5 Product Name List): overcharge detect **4.300 ±0.050 V**,
release **4.100 ±0.050 V**; overdischarge detect **2.40 ±0.100 V**, release
**3.0 ±0.100 V**; overcurrent detect **150 ±30 mV**. Quiescent current 3 µA at
Vcc = 3.9 V. Delay times are generated internally — **no external capacitors
required**.

Note the datasheet's own footer reads "For Reference Only", which is worth
knowing before designing a safety circuit around it.

### FS8205A — dual N-channel MOSFET (the actual cell-current switch) ❌ U

**Pinout NOT verified.** Only distributor listings and datasheet-aggregator
pages were reachable; **no manufacturer pin-configuration table was
obtained.** Sources disagree on which pins carry S1/S2 and on whether the
drains are internally common. Manufacturer is FuxinSemi, package SOT-23-6L,
document Ver. 2.1 (2018) per one aggregator — the document itself was not
retrieved.

**Consequence:** the DW01A + FS8205A protection circuit **still cannot be
added responsibly**, because the FS8205A is the part carrying the full cell
current. See `REQUIRES_CONFIRMATION.md` **B1**.

### AS5600 3.3 V-mode strapping ✅ confirmed

Not a new part — a confirmation that closes **M5**. *AS5600 Datasheet,
ams-OSRAM, [v1-06] 2018-Jun-20*, page 9: "In 3.3V operation, the VDD5V and
VDD3V3 pins must be tied together. VDD is the voltage level present at the
VDD5V pin." The board does exactly that. Per-pin decoupling (page 3) also
matches: 100 nF on `VDD5V`, 1 µF on `VDD3V3`.

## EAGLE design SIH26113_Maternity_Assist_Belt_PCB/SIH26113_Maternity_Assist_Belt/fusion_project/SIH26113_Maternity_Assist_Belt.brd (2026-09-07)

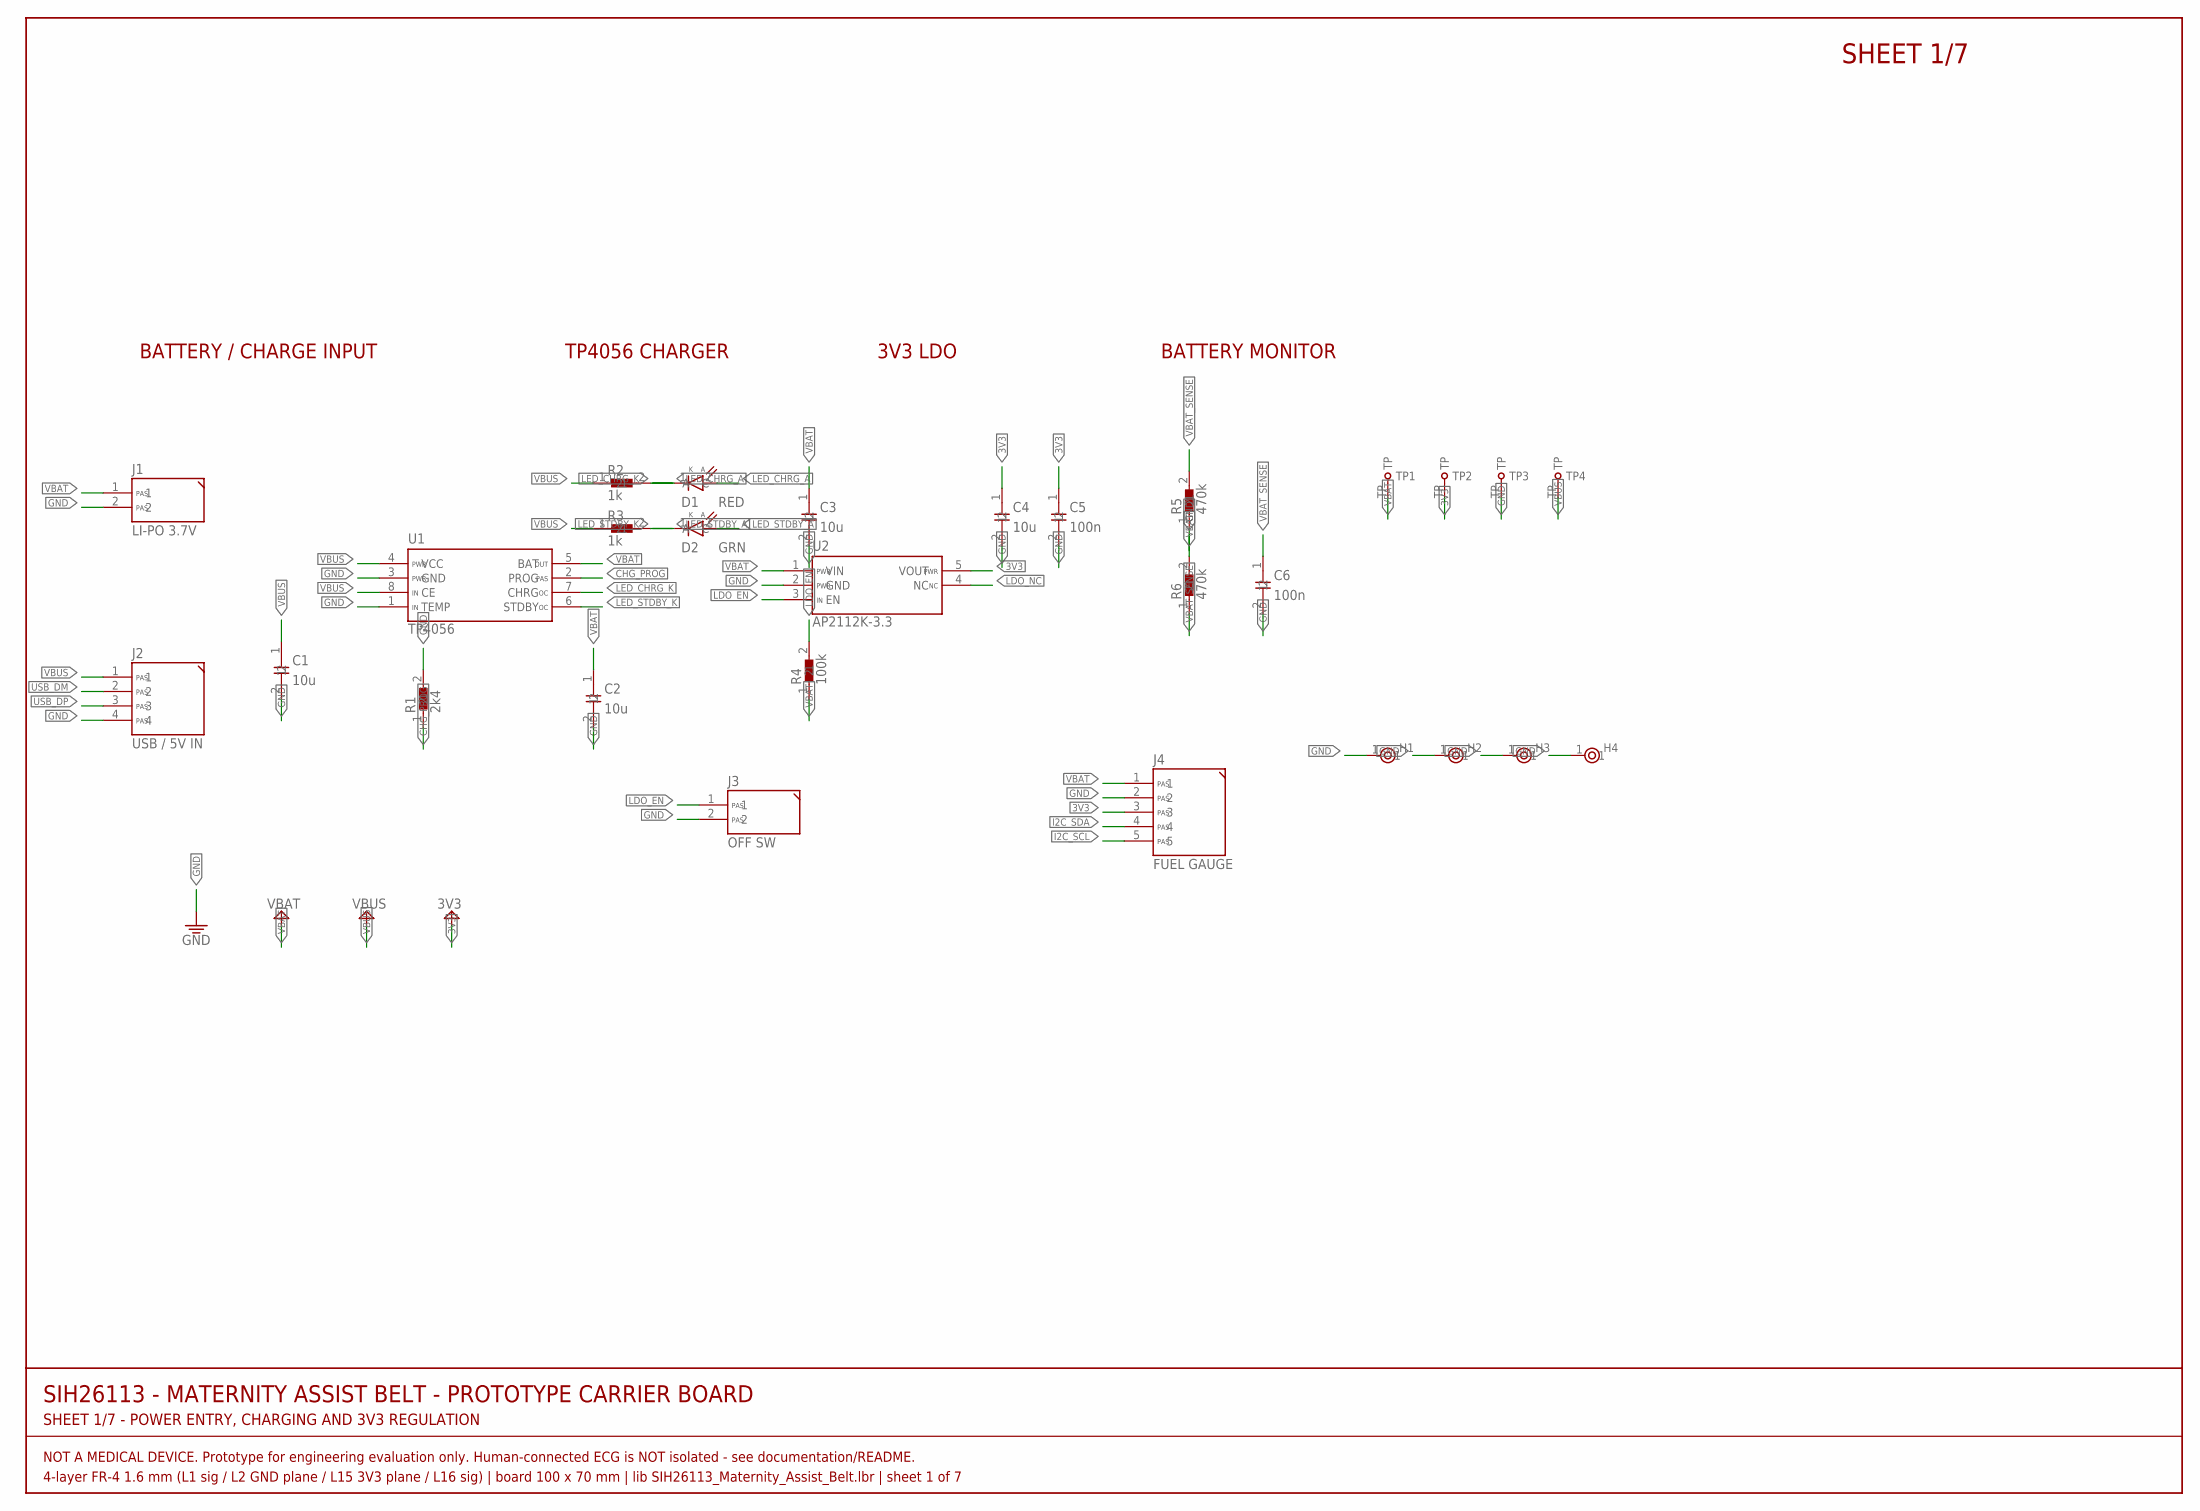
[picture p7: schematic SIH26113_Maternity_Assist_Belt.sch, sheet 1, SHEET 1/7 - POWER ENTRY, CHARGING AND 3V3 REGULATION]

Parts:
C1, C2, C3, C4: 10u; C0805
C5, C6: 100n; C0805
D1: RED; LED0805
D2: GRN; LED0805
H1, H2, H3, H4: M2; MOUNT-M2
J1: LI-PO 3.7V; JST-PH-2
J2: USB / 5V IN; HDR-1X4
J3: OFF SW; HDR-1X2
J4: FUEL GAUGE; HDR-1X5
R1: 2k4; R0805
R2, R3: 1k; R0805
R4: 100k; R0805
R5, R6: 470k; R0805
TP1: VBAT; TESTPOINT-1.5
TP2: 3V3; TESTPOINT-1.5
TP3: GND; TESTPOINT-1.5
TP4: VBUS; TESTPOINT-1.5
U1: TP4056; SOIC-8-N
U2: AP2112K-3.3; SOT-23-5

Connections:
3V3: C4.1, C5.1, J4.3, TP2.TP, U2.5 (VOUT); also elsewhere on the board
CHG_PROG: R1.1, U1.2 (PROG)
GND: C1.2, C2.2, C3.2, C4.2, C5.2, C6.2, H1.1, H2.1, H3.1, H4.1, J1.2, J2.4, J3.2, J4.2, R1.2, R6.2, TP3.TP, U1.1 (TEMP), U1.3 (GND), U2.2 (GND); also elsewhere on the board
I2C_SCL: J4.5; also elsewhere on the board
I2C_SDA: J4.4; also elsewhere on the board
LDO_EN: J3.1, R4.2, U2.3 (EN)
LDO_NC: U2.4 (NC)
LED_CHRG_A: D1.2 (A), R2.2
LED_CHRG_K: D1.1 (C), U1.7 (CHRG)
LED_STDBY_A: D2.2 (A), R3.2
LED_STDBY_K: D2.1 (C), U1.6 (STDBY)
USB_DM: J2.2; also elsewhere on the board
USB_DP: J2.3; also elsewhere on the board
VBAT: C2.1, C3.1, J1.1, J4.1, R4.1, R5.1, TP1.TP, U1.5 (BAT), U2.1 (VIN); also elsewhere on the board
VBAT_SENSE: C6.1, R5.2, R6.1; also elsewhere on the board
VBUS: C1.1, J2.1, R2.1, R3.1, TP4.TP, U1.4 (VCC), U1.8 (CE)

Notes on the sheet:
SIH26113 - MATERNITY ASSIST BELT - PROTOTYPE CARRIER BOARD
SHEET 1/7 - POWER ENTRY, CHARGING AND 3V3 REGULATION
NOT A MEDICAL DEVICE. Prototype for engineering evaluation only. Human-connected ECG is NOT isolated - see documentation/README.
4-layer FR-4 1.6 mm (L1 sig / L2 GND plane / L15 3V3 plane / L16 sig) | board 100 x 70 mm | lib SIH26113_Maternity_Assist_Belt.lbr | sheet 1 of 7
SHEET 1/7
BATTERY / CHARGE INPUT
TP4056 CHARGER
3V3 LDO
BATTERY MONITOR

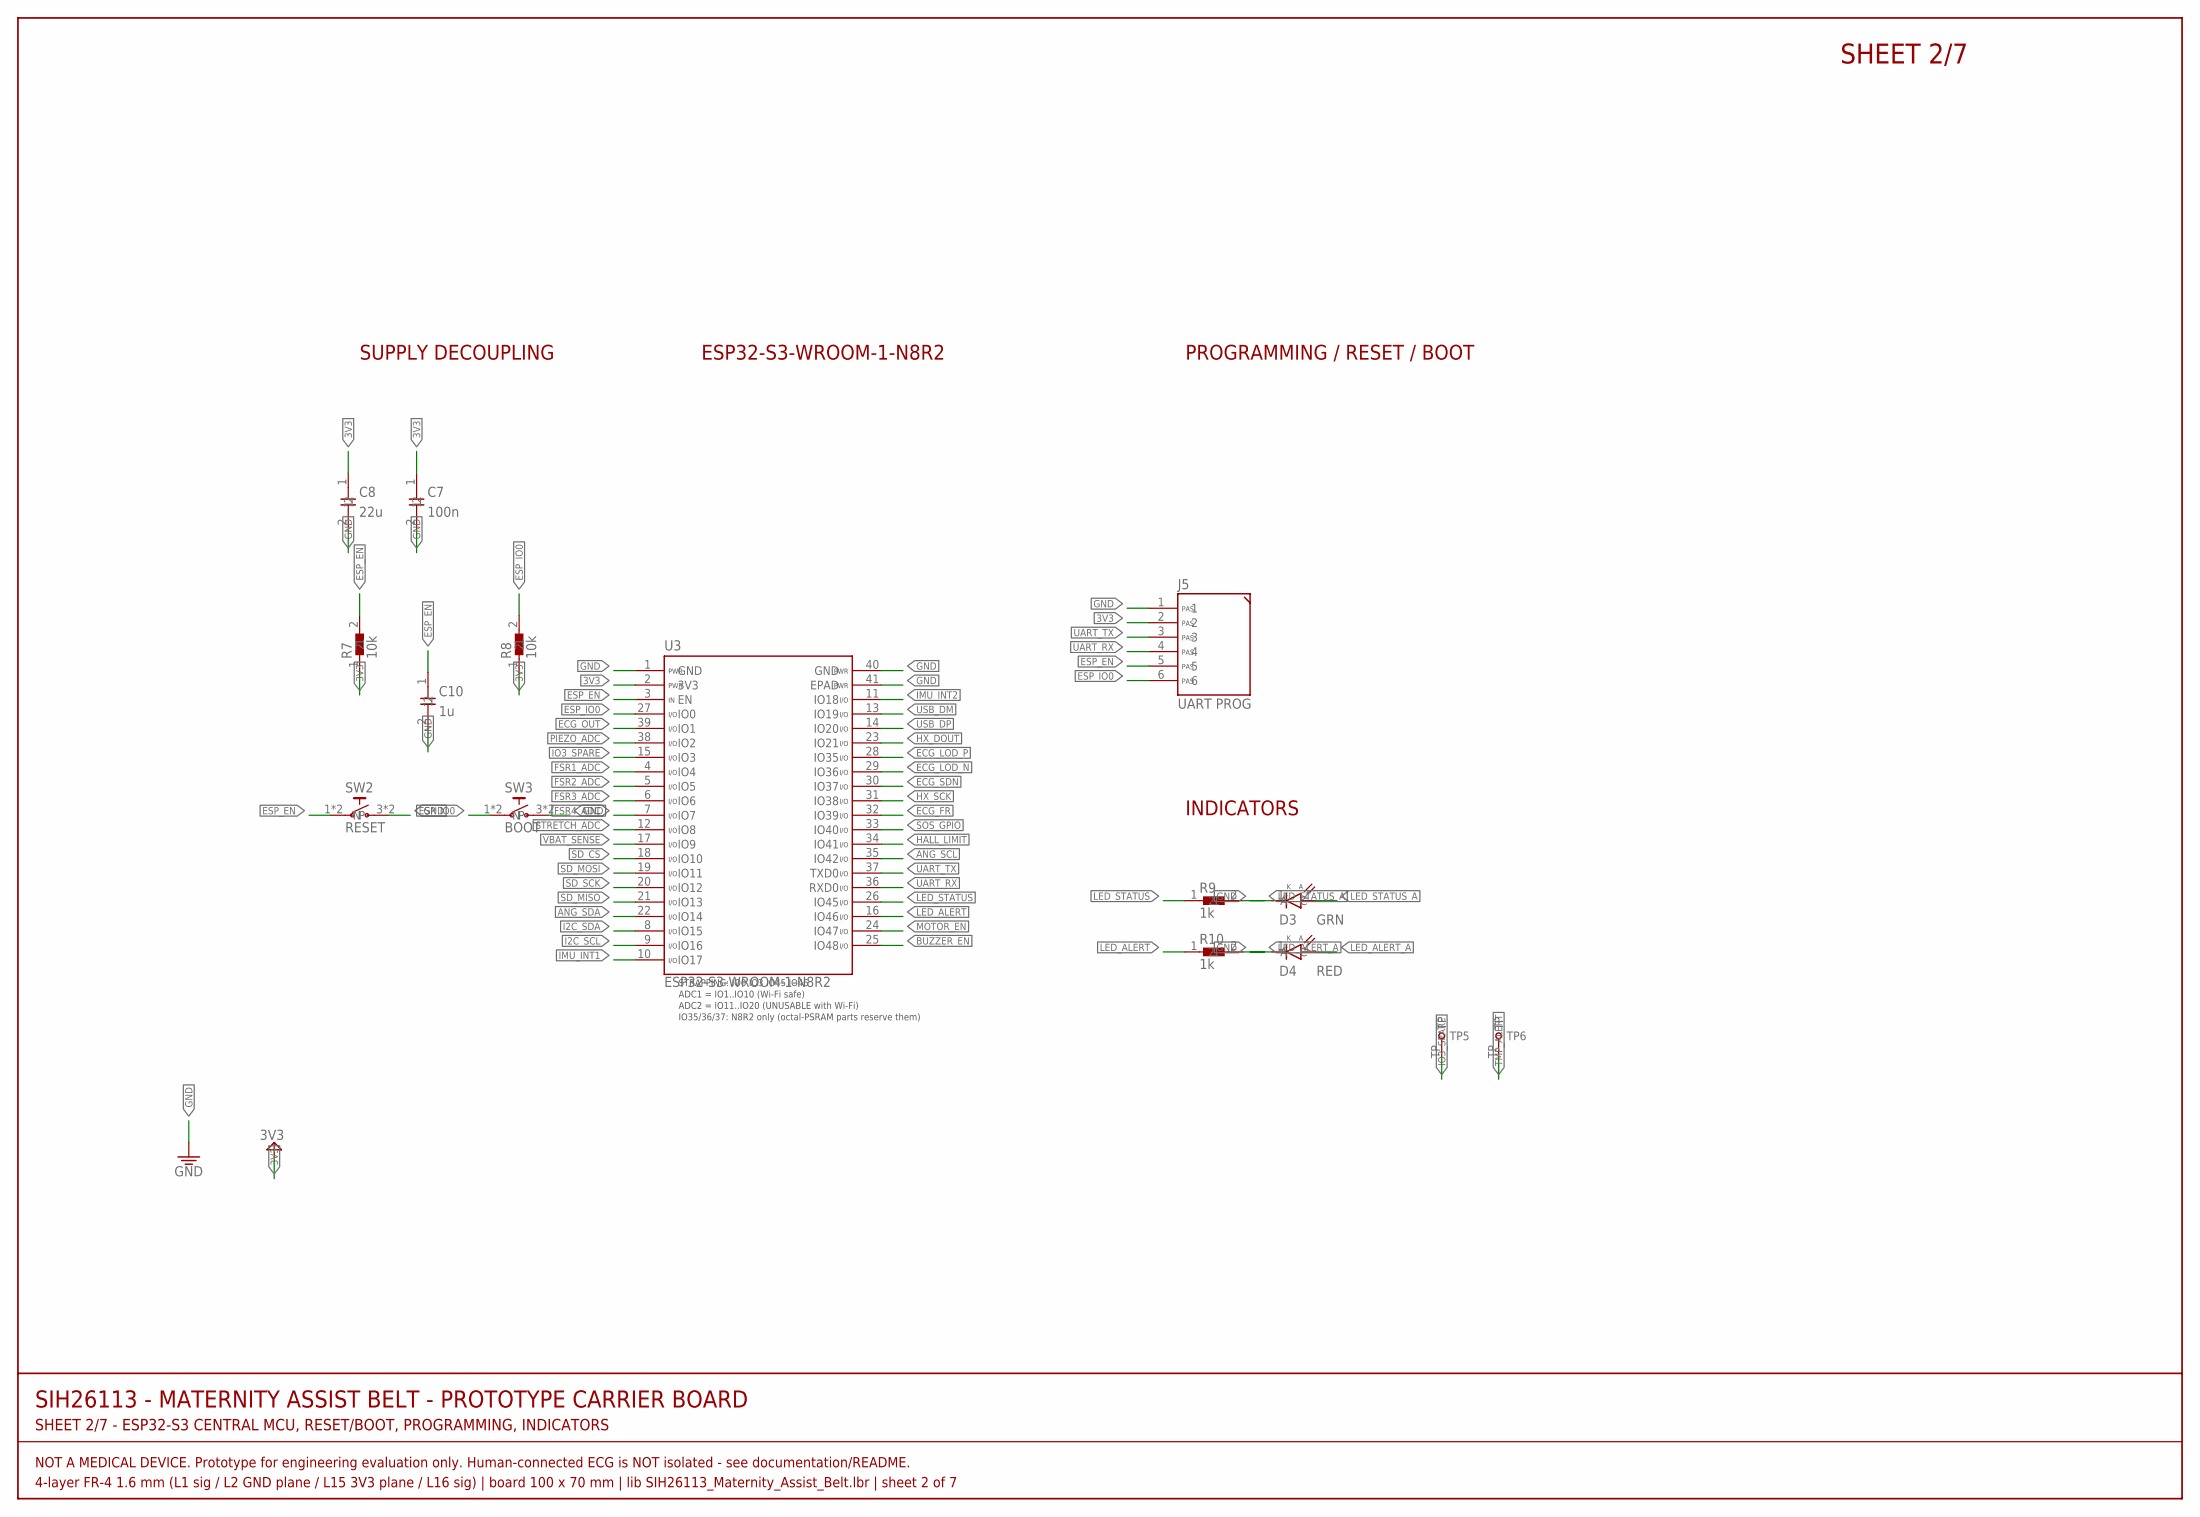
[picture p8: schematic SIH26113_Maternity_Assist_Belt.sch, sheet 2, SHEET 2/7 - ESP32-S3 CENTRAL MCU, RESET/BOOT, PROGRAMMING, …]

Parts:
C7: 100n; C0805
C8: 22u; C0805
C10: 1u; C0805
D3: GRN; LED0805
D4: RED; LED0805
J5: UART PROG; HDR-1X6
R7, R8: 10k; R0805
R9, R10: 1k; R0805
SW2: RESET; TACT-6X6-THT
SW3: BOOT; TACT-6X6-THT
TP5: IO3; TESTPOINT-1.5
TP6: TMP_ALERT; TESTPOINT-1.5
U3: ESP32-S3-WROOM-1-N8R2; ESP32-S3-WROOM-1

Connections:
3V3: C7.1, C8.1, J5.2, R7.1, R8.1, U3.2 (3V3); also elsewhere on the board
ANG_SCL: U3.35 (IO42); also elsewhere on the board
ANG_SDA: U3.22 (IO14); also elsewhere on the board
BUZZER_EN: U3.25 (IO48); also elsewhere on the board
ECG_FR: U3.32 (IO39); also elsewhere on the board
ECG_LOD_N: U3.29 (IO36); also elsewhere on the board
ECG_LOD_P: U3.28 (IO35); also elsewhere on the board
ECG_OUT: U3.39 (IO1); also elsewhere on the board
ECG_SDN: U3.30 (IO37); also elsewhere on the board
ESP_EN: C10.1, J5.5, R7.2, SW2.1, SW2.2, U3.3 (EN)
ESP_IO0: J5.6, R8.2, SW3.1, SW3.2, U3.27 (IO0)
FSR1_ADC: U3.4 (IO4); also elsewhere on the board
FSR2_ADC: U3.5 (IO5); also elsewhere on the board
FSR3_ADC: U3.6 (IO6); also elsewhere on the board
FSR4_ADC: U3.7 (IO7); also elsewhere on the board
GND: C7.2, C8.2, C10.2, D3.1 (C), D4.1 (C), J5.1, SW2.3 (N), SW2.4 (N), SW3.3 (N), SW3.4 (N), U3.1 (GND), U3.40 (GND), U3.41 (EPAD); also elsewhere on the board
HALL_LIMIT: U3.34 (IO41); also elsewhere on the board
HX_DOUT: U3.23 (IO21); also elsewhere on the board
HX_SCK: U3.31 (IO38); also elsewhere on the board
I2C_SCL: U3.9 (IO16); also elsewhere on the board
I2C_SDA: U3.8 (IO15); also elsewhere on the board
IMU_INT1: U3.10 (IO17); also elsewhere on the board
IMU_INT2: U3.11 (IO18); also elsewhere on the board
IO3_SPARE: TP5.TP, U3.15 (IO3); also elsewhere on the board
LED_ALERT: R10.1, U3.16 (IO46)
LED_ALERT_A: D4.2 (A), R10.2
LED_STATUS: R9.1, U3.26 (IO45)
LED_STATUS_A: D3.2 (A), R9.2
MOTOR_EN: U3.24 (IO47); also elsewhere on the board
PIEZO_ADC: U3.38 (IO2); also elsewhere on the board
SD_CS: U3.18 (IO10); also elsewhere on the board
SD_MISO: U3.21 (IO13); also elsewhere on the board
SD_MOSI: U3.19 (IO11); also elsewhere on the board
SD_SCK: U3.20 (IO12); also elsewhere on the board
SOS_GPIO: U3.33 (IO40); also elsewhere on the board
STRETCH_ADC: U3.12 (IO8); also elsewhere on the board
TMP_ALERT: TP6.TP; also elsewhere on the board
UART_RX: J5.4, U3.36 (RXD0)
UART_TX: J5.3, U3.37 (TXD0)
USB_DM: U3.13 (IO19); also elsewhere on the board
USB_DP: U3.14 (IO20); also elsewhere on the board
VBAT_SENSE: U3.17 (IO9); also elsewhere on the board

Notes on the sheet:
SIH26113 - MATERNITY ASSIST BELT - PROTOTYPE CARRIER BOARD
SHEET 2/7 - ESP32-S3 CENTRAL MCU, RESET/BOOT, PROGRAMMING, INDICATORS
NOT A MEDICAL DEVICE. Prototype for engineering evaluation only. Human-connected ECG is NOT isolated - see documentation/README.
4-layer FR-4 1.6 mm (L1 sig / L2 GND plane / L15 3V3 plane / L16 sig) | board 100 x 70 mm | lib SIH26113_Maternity_Assist_Belt.lbr | sheet 2 of 7
SHEET 2/7
SUPPLY DECOUPLING
ESP32-S3-WROOM-1-N8R2
PROGRAMMING / RESET / BOOT
INDICATORS

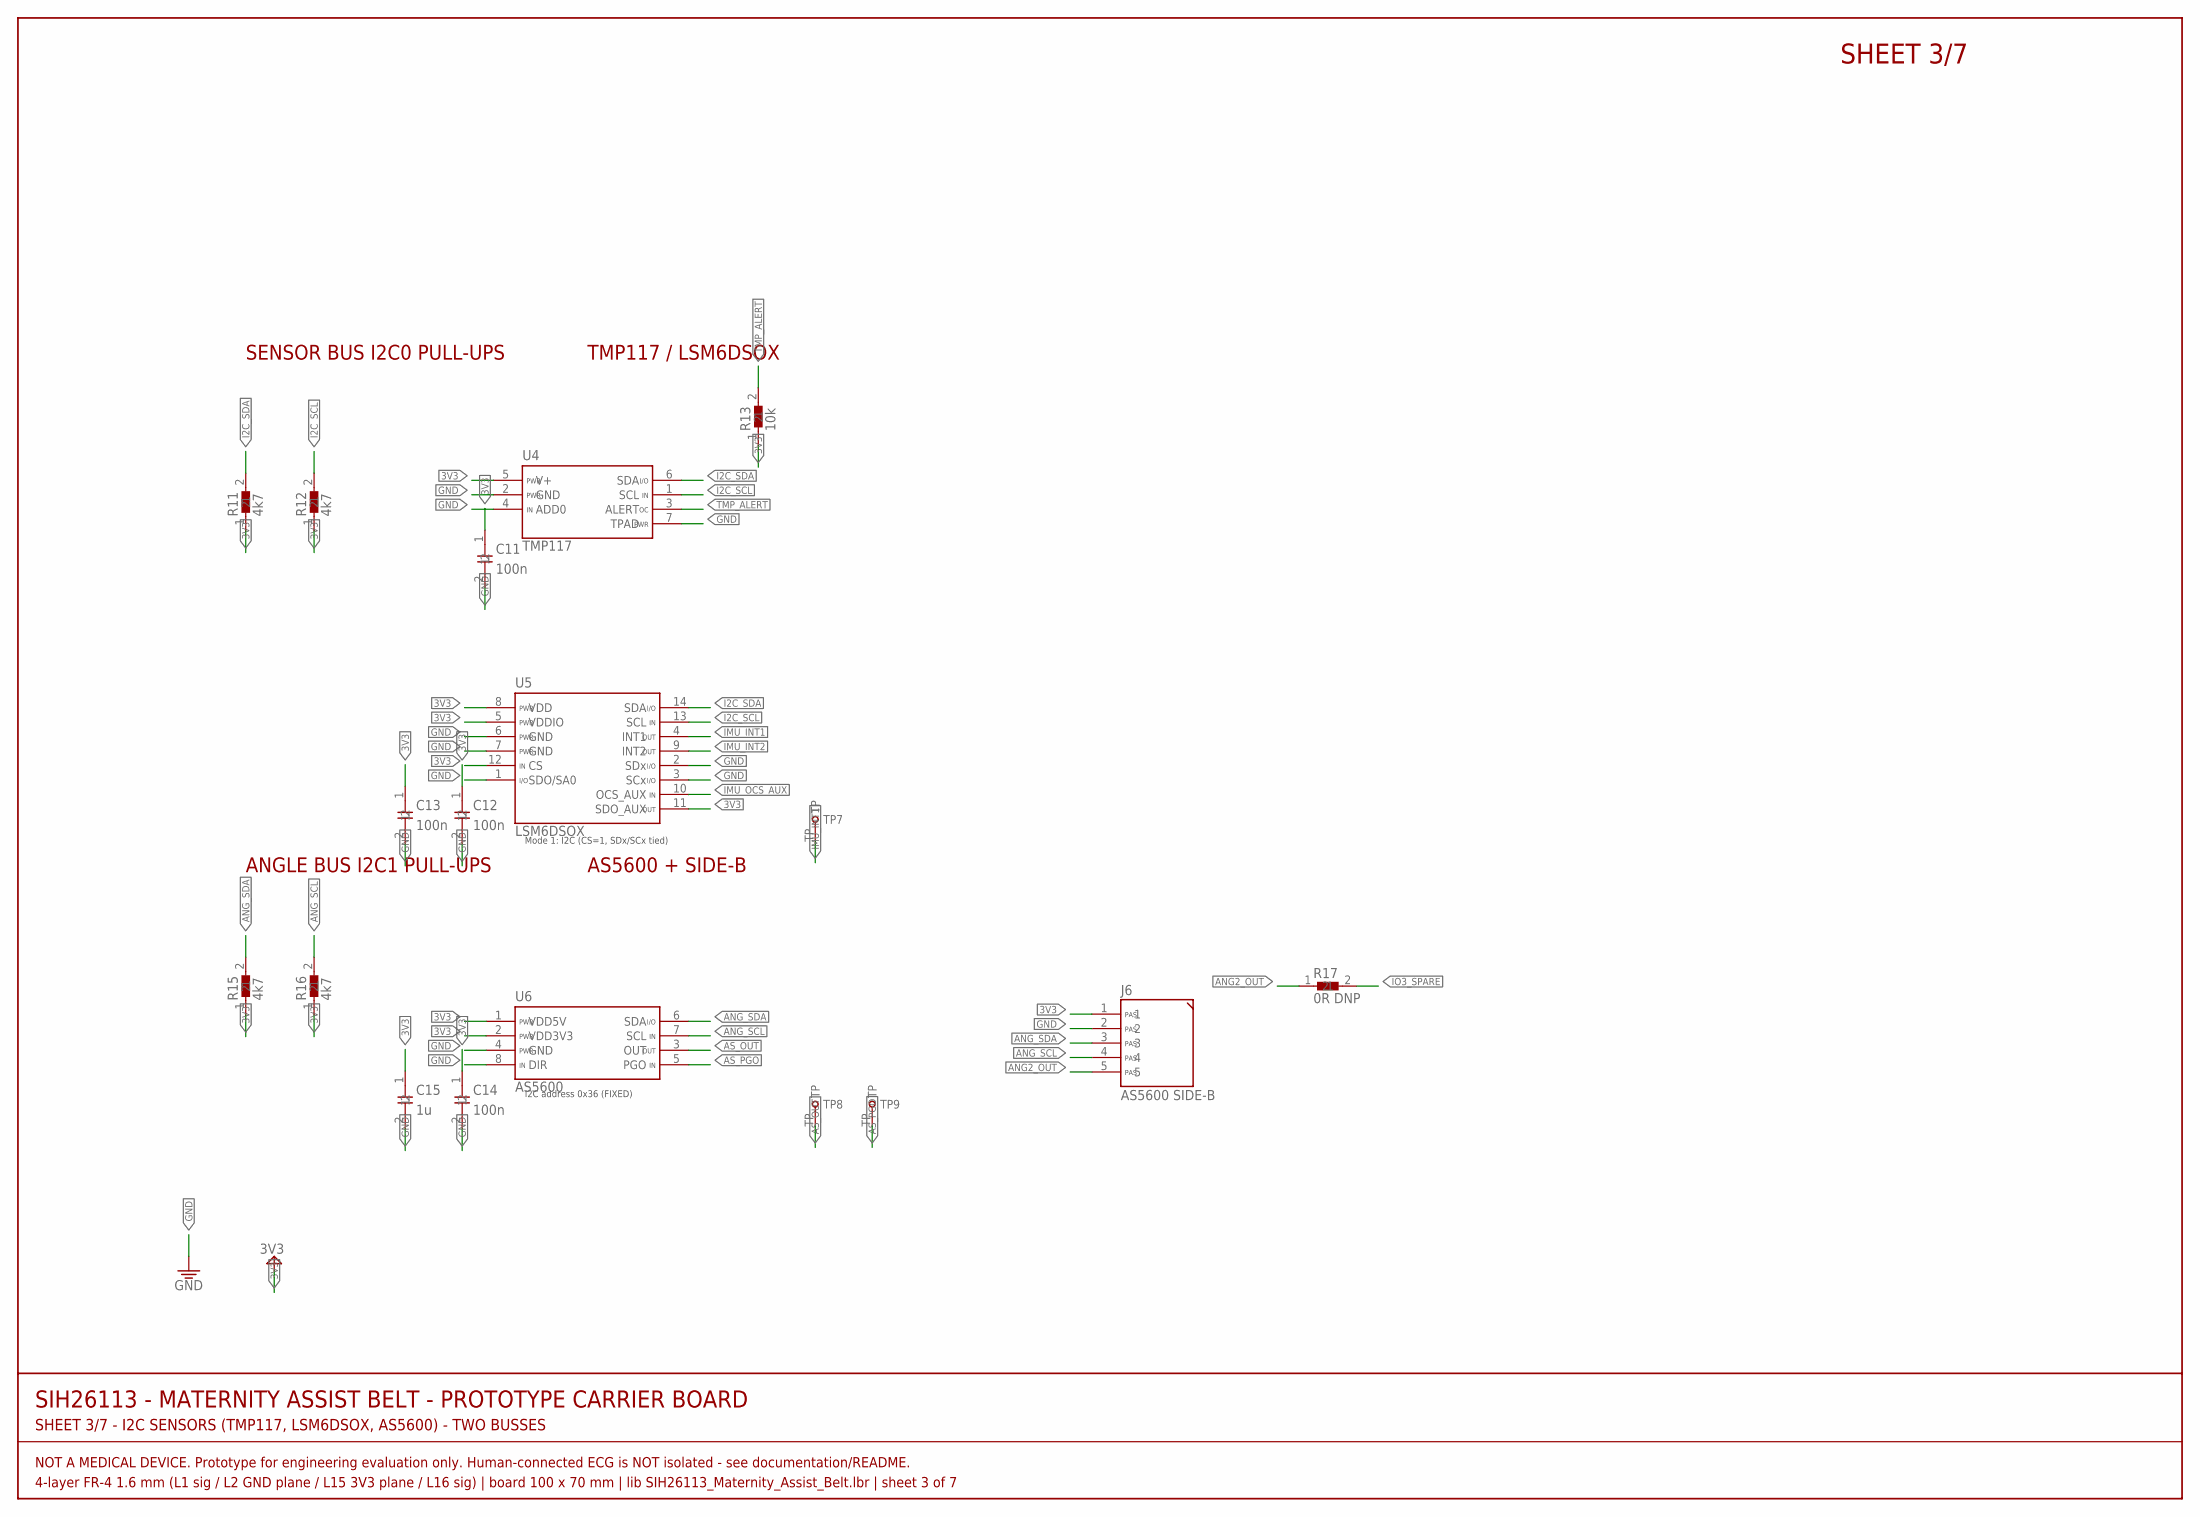
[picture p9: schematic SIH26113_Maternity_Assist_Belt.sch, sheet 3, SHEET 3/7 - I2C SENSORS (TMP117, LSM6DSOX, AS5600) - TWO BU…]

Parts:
C11, C12, C13, C14: 100n; C0805
C15: 1u; C0805
J6: AS5600 SIDE-B; HDR-1X5
R11, R12, R15, R16: 4k7; R0805
R13: 10k; R0805
R17: 0R DNP; R0805
TP7: IMU_INT1; TESTPOINT-1.5
TP8: AS_OUT; TESTPOINT-1.5
TP9: AS_PGO; TESTPOINT-1.5
U4: TMP117; WSON-6-DRV0006B
U5: LSM6DSOX; LGA-14L-2.5X3.0
U6: AS5600; SOIC-8-N

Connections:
3V3: C11.1, C12.1, C13.1, C14.1, C15.1, J6.1, R11.1, R12.1, R13.1, R15.1, R16.1, U4.5 (V+), U5.5 (VDDIO), U5.8 (VDD), U5.11 (SDO_AUX), U5.12 (CS), U6.1 (VDD5V), U6.2 (VDD3V3); also elsewhere on the board
ANG2_OUT: J6.5, R17.1
ANG_SCL: J6.4, R16.2, U6.7 (SCL); also elsewhere on the board
ANG_SDA: J6.3, R15.2, U6.6 (SDA); also elsewhere on the board
AS_OUT: TP8.TP, U6.3 (OUT)
AS_PGO: TP9.TP, U6.5 (PGO)
GND: C11.2, C12.2, C13.2, C14.2, C15.2, J6.2, U4.2 (GND), U4.4 (ADD0), U4.7 (TPAD), U5.1 (SDO/SA0), U5.2 (SDx), U5.3 (SCx), U5.6 (GND), U5.7 (GND), U6.4 (GND), U6.8 (DIR); also elsewhere on the board
I2C_SCL: R12.2, U4.1 (SCL), U5.13 (SCL); also elsewhere on the board
I2C_SDA: R11.2, U4.6 (SDA), U5.14 (SDA); also elsewhere on the board
IMU_INT1: TP7.TP, U5.4 (INT1); also elsewhere on the board
IMU_INT2: U5.9 (INT2); also elsewhere on the board
IMU_OCS_AUX: U5.10 (OCS_AUX)
IO3_SPARE: R17.2; also elsewhere on the board
TMP_ALERT: R13.2, U4.3 (ALERT); also elsewhere on the board

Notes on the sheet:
SIH26113 - MATERNITY ASSIST BELT - PROTOTYPE CARRIER BOARD
SHEET 3/7 - I2C SENSORS (TMP117, LSM6DSOX, AS5600) - TWO BUSSES
NOT A MEDICAL DEVICE. Prototype for engineering evaluation only. Human-connected ECG is NOT isolated - see documentation/README.
4-layer FR-4 1.6 mm (L1 sig / L2 GND plane / L15 3V3 plane / L16 sig) | board 100 x 70 mm | lib SIH26113_Maternity_Assist_Belt.lbr | sheet 3 of 7
SHEET 3/7
SENSOR BUS I2C0 PULL-UPS
TMP117 / LSM6DSOX
ANGLE BUS I2C1 PULL-UPS
AS5600 + SIDE-B

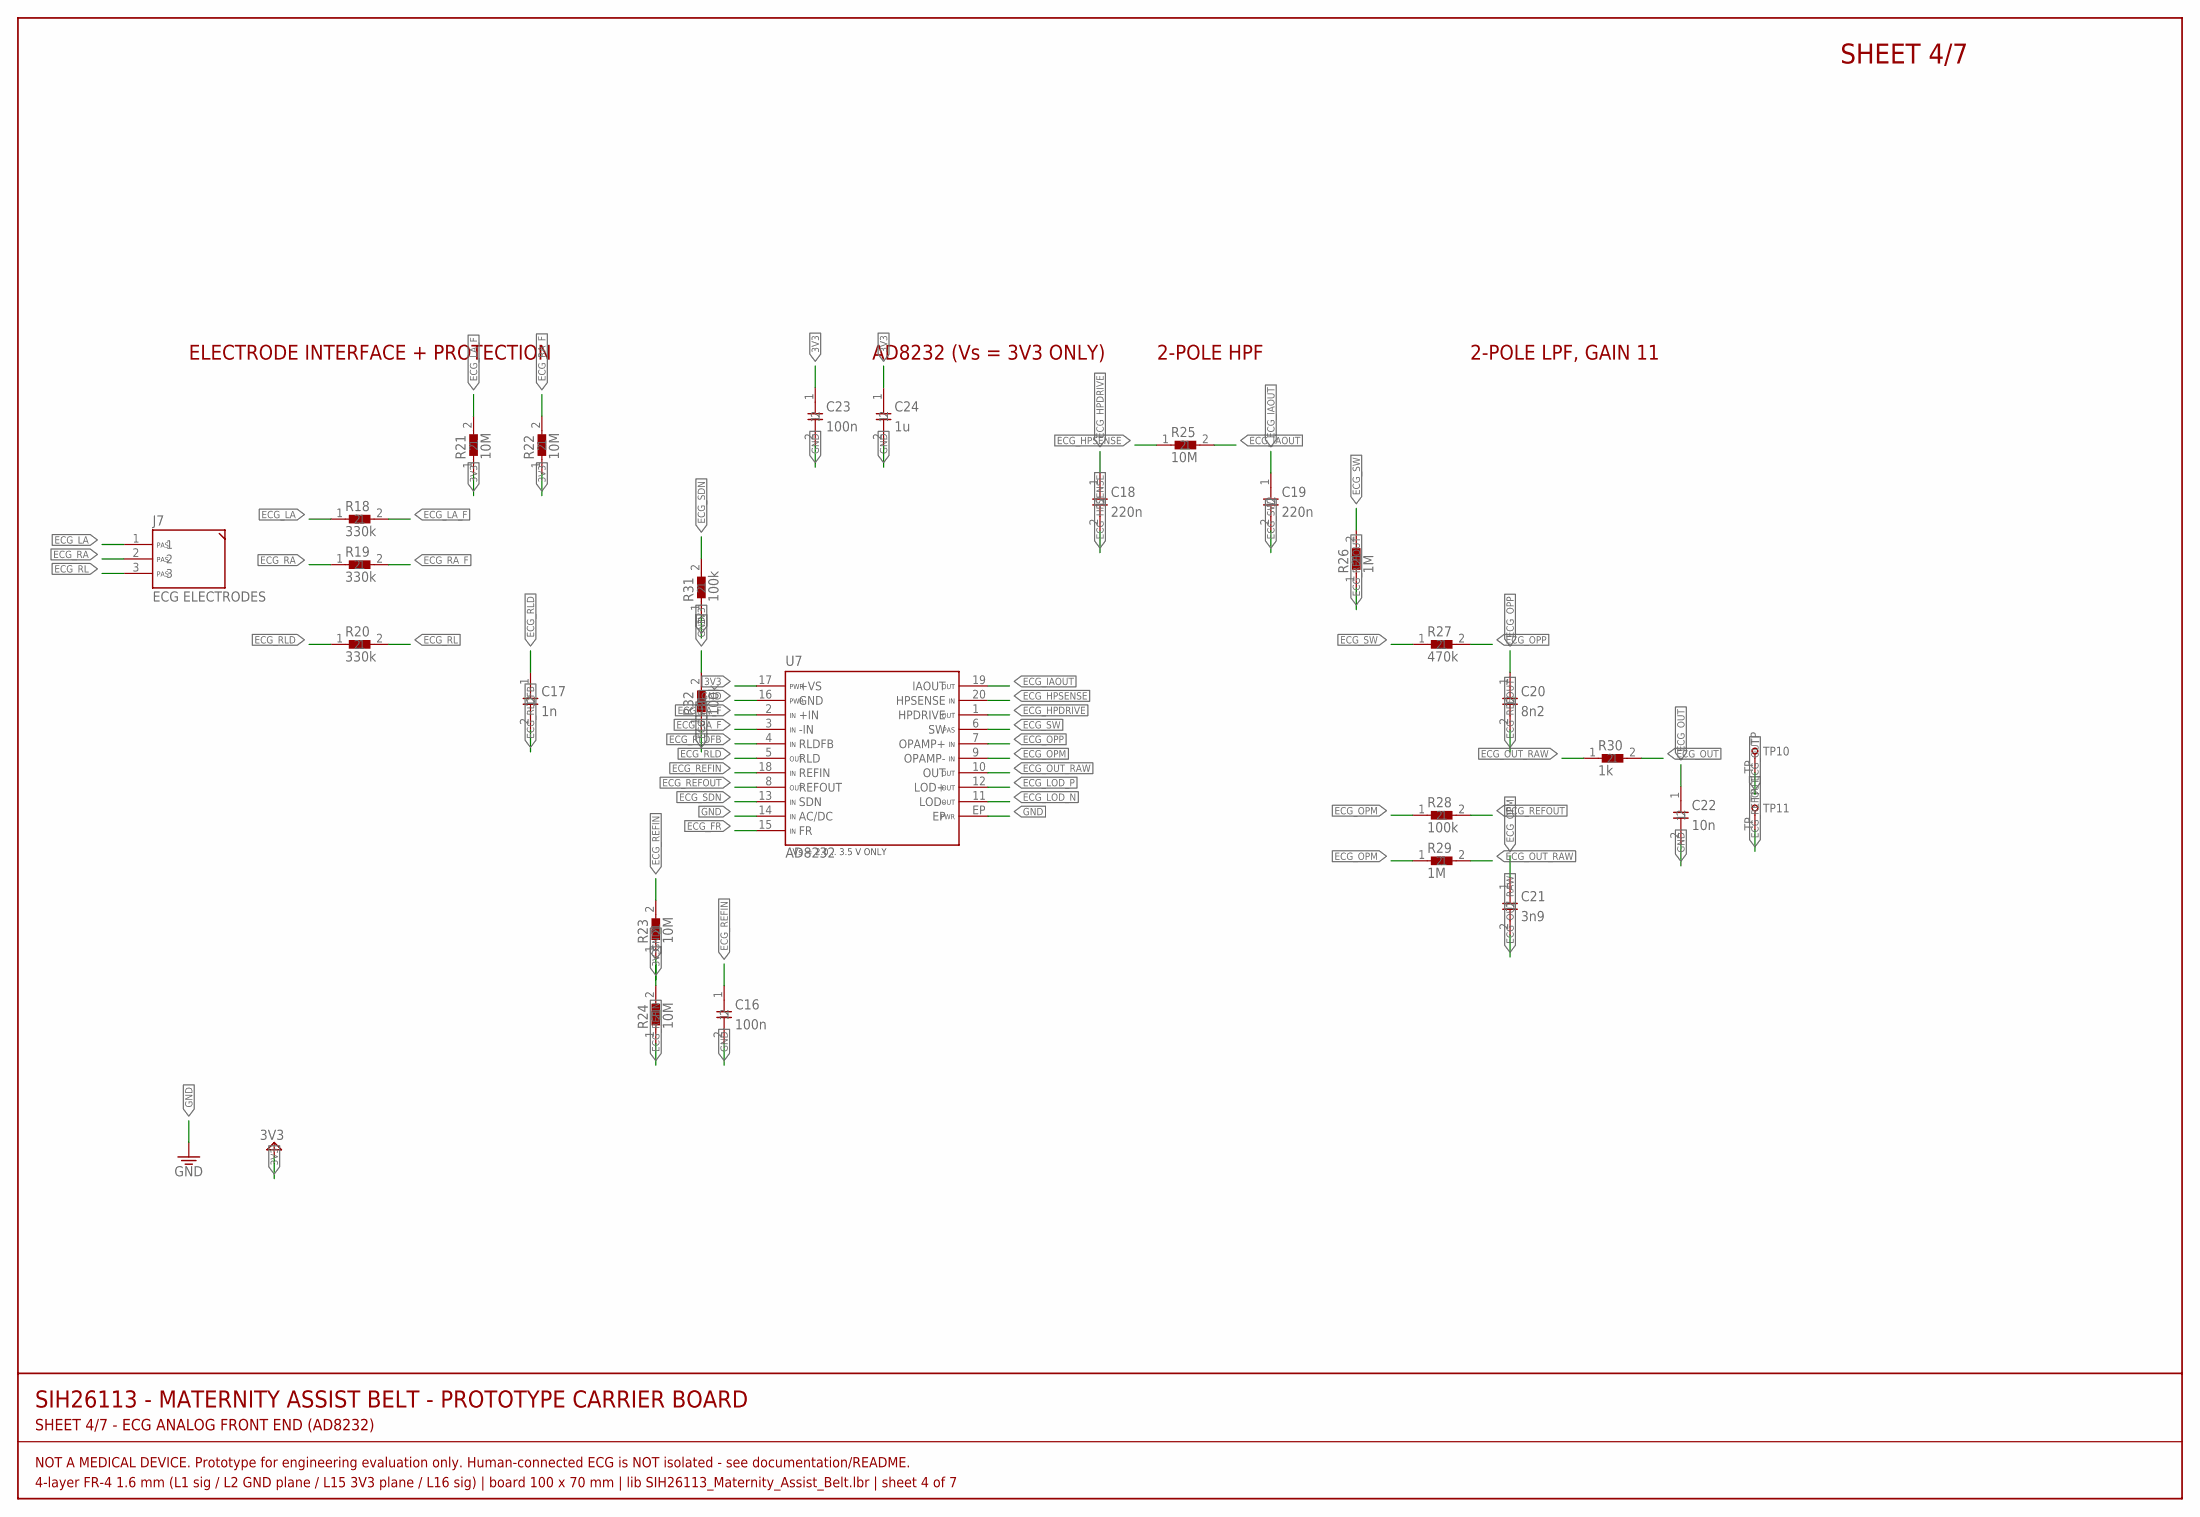
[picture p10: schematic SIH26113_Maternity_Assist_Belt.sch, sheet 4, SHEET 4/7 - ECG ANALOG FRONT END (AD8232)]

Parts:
C16, C23: 100n; C0805
C17: 1n; C0805
C18, C19: 220n; C0805
C20: 8n2; C0805
C21: 3n9; C0805
C22: 10n; C0805
C24: 1u; C0805
J7: ECG ELECTRODES; HDR-1X3
R18, R19, R20: 330k; R0805
R21, R22, R23, R24, R25: 10M; R0805
R26, R29: 1M; R0805
R27: 470k; R0805
R28, R31, R32: 100k; R0805
R30: 1k; R0805
TP10: ECG_OUT; TESTPOINT-1.5
TP11: ECG_REF; TESTPOINT-1.5
U7: AD8232; LFCSP-20-4X4-P050

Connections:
3V3: C23.1, C24.1, R21.1, R22.1, R23.1, R31.1, U7.17 (+VS); also elsewhere on the board
ECG_FR: R32.1, U7.15 (FR); also elsewhere on the board
ECG_HPDRIVE: C18.1, U7.1 (HPDRIVE)
ECG_HPSENSE: C18.2, R25.1, U7.20 (HPSENSE)
ECG_IAOUT: C19.1, R25.2, U7.19 (IAOUT)
ECG_LA: J7.1, R18.1
ECG_LA_F: R18.2, R21.2, U7.2 (+IN)
ECG_LOD_N: U7.11 (LOD-); also elsewhere on the board
ECG_LOD_P: U7.12 (LOD+); also elsewhere on the board
ECG_OPM: C21.1, R28.1, R29.1, U7.9 (OPAMP-)
ECG_OPP: C20.1, R27.2, U7.7 (OPAMP+)
ECG_OUT: C22.1, R30.2, TP10.TP; also elsewhere on the board
ECG_OUT_RAW: C21.2, R29.2, R30.1, U7.10 (OUT)
ECG_RA: J7.2, R19.1
ECG_RA_F: R19.2, R22.2, U7.3 (-IN)
ECG_REFIN: C16.1, R23.2, R24.1, U7.18 (REFIN)
ECG_REFOUT: C20.2, R26.1, R28.2, TP11.TP, U7.8 (REFOUT)
ECG_RL: J7.3, R20.2
ECG_RLD: C17.1, R20.1, U7.5 (RLD)
ECG_RLDFB: C17.2, U7.4 (RLDFB)
ECG_SDN: R31.2, U7.13 (SDN); also elsewhere on the board
ECG_SW: C19.2, R26.2, R27.1, U7.6 (SW)
GND: C16.2, C22.2, C23.2, C24.2, R24.2, R32.2, U7.14 (AC/DC), U7.16 (GND), U7.EP; also elsewhere on the board

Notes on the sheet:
SIH26113 - MATERNITY ASSIST BELT - PROTOTYPE CARRIER BOARD
SHEET 4/7 - ECG ANALOG FRONT END (AD8232)
NOT A MEDICAL DEVICE. Prototype for engineering evaluation only. Human-connected ECG is NOT isolated - see documentation/README.
4-layer FR-4 1.6 mm (L1 sig / L2 GND plane / L15 3V3 plane / L16 sig) | board 100 x 70 mm | lib SIH26113_Maternity_Assist_Belt.lbr | sheet 4 of 7
SHEET 4/7
ELECTRODE INTERFACE + PROTECTION
AD8232 (Vs = 3V3 ONLY)
2-POLE HPF
2-POLE LPF, GAIN 11

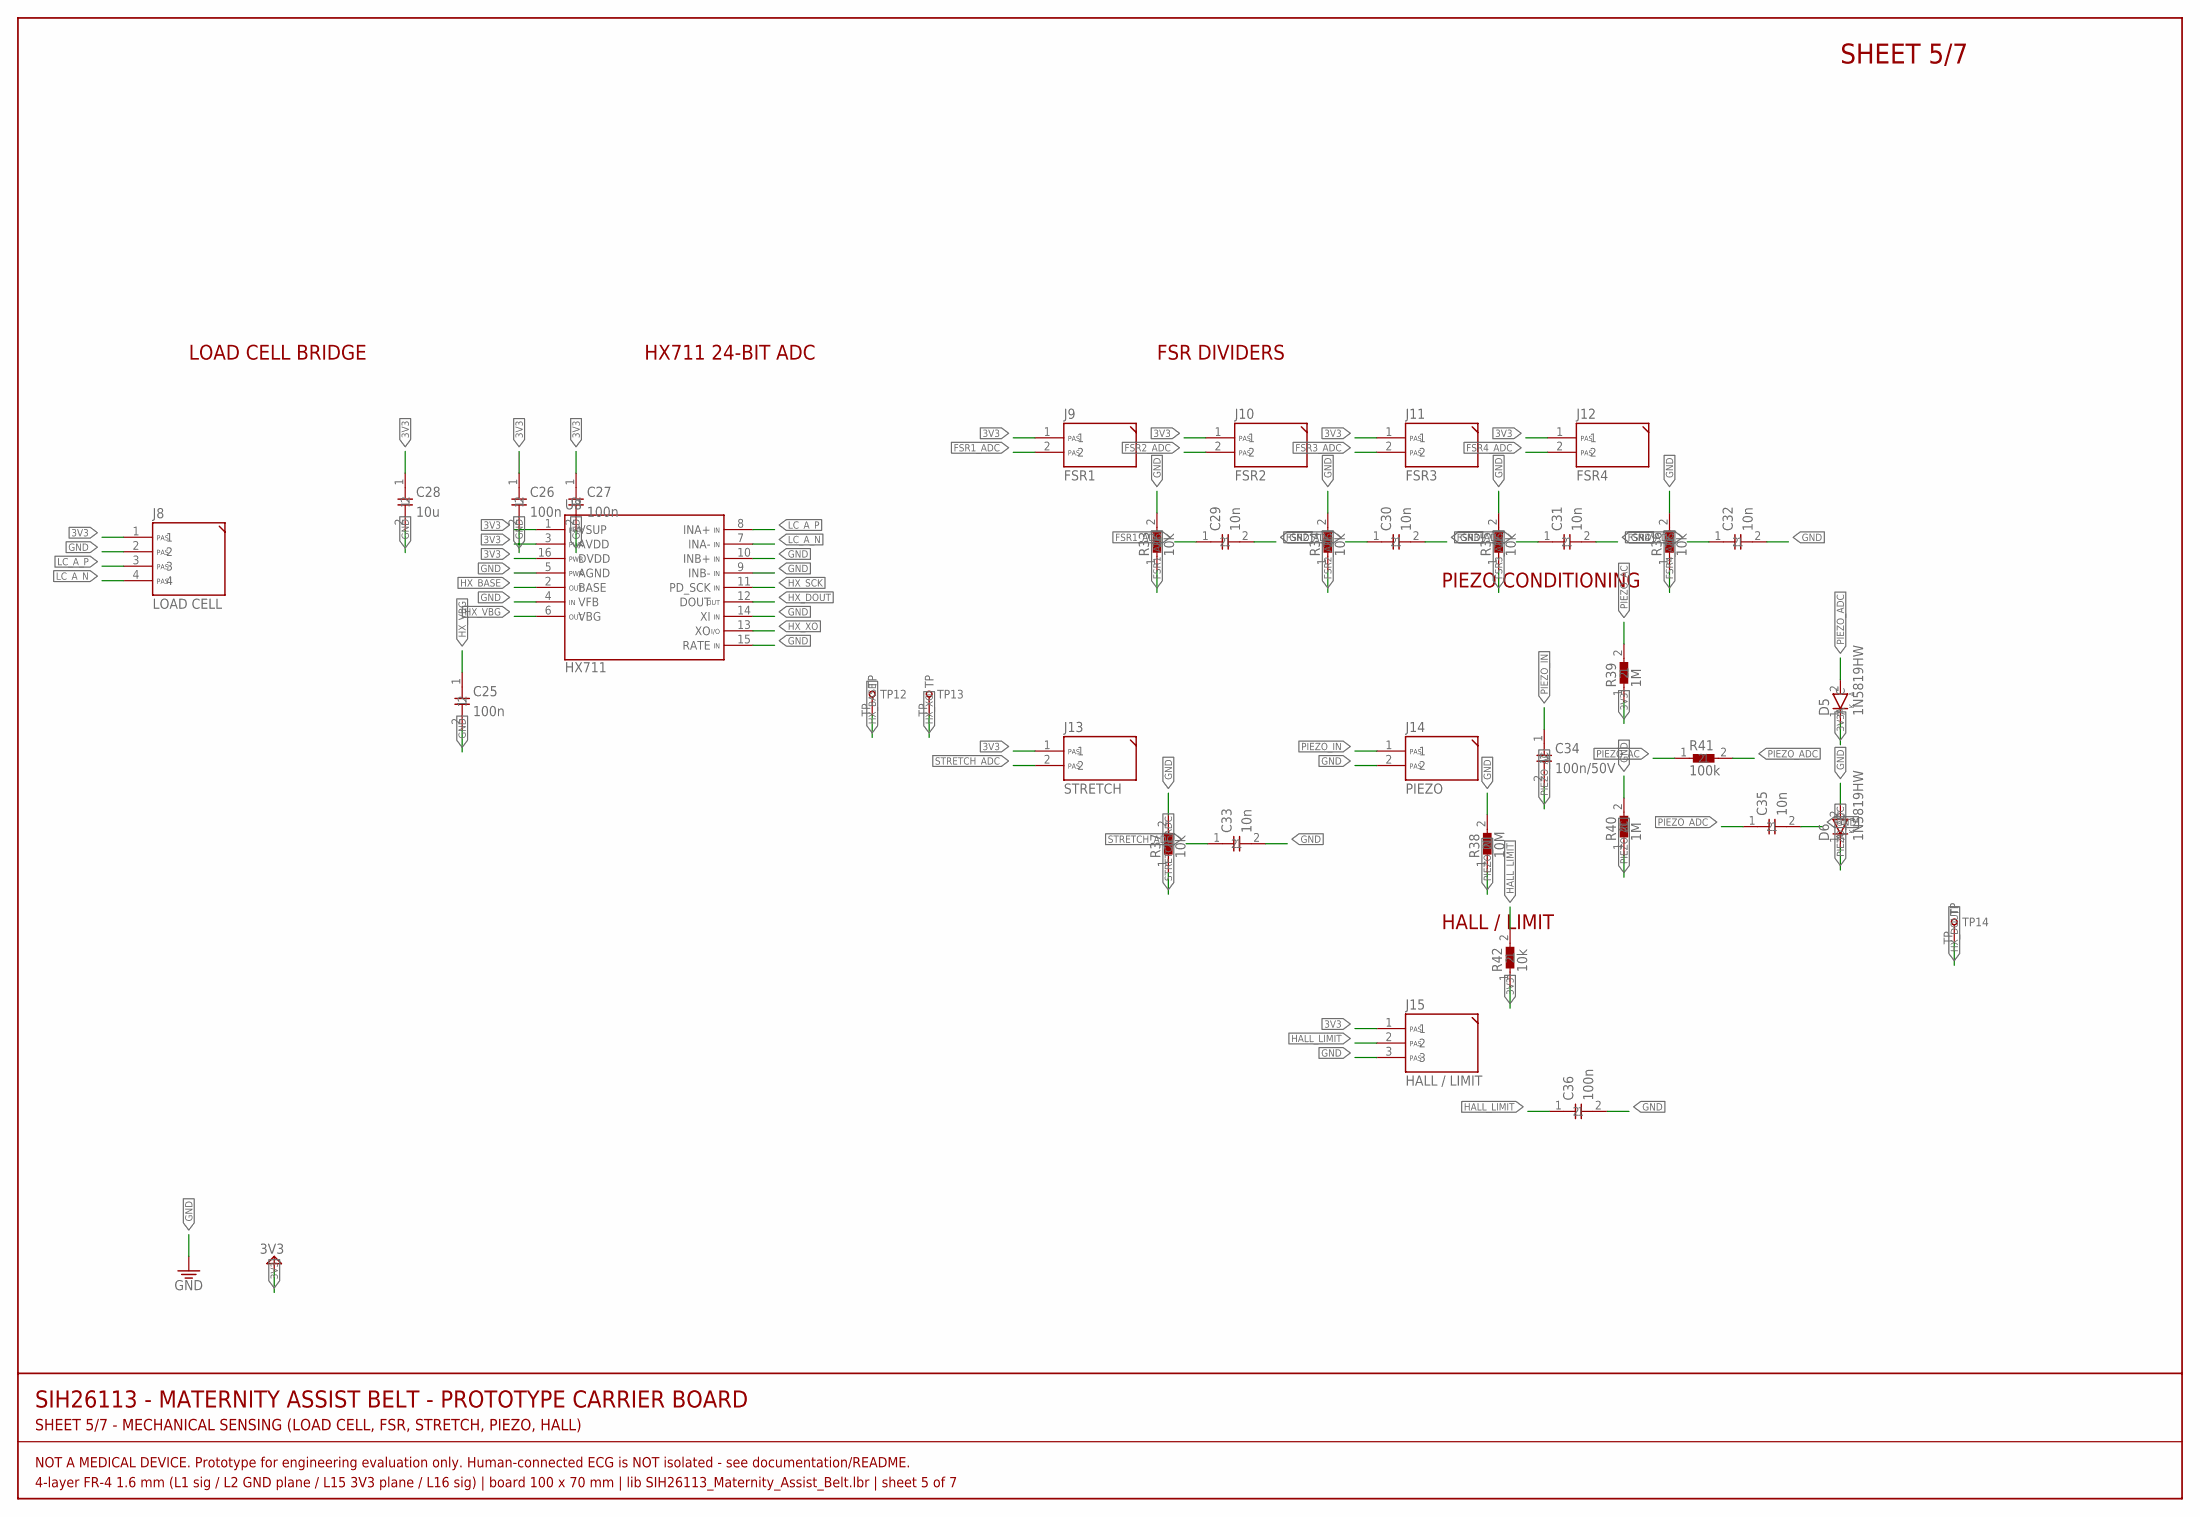
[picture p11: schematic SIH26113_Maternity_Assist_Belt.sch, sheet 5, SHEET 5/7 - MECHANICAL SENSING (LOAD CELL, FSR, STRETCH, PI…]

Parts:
C25, C26, C27, C36: 100n; C0805
C28: 10u; C0805
C29, C30, C31, C32, C33, C35: 10n; C0805
C34: 100n/50V; C0805
D5, D6: 1N5819HW; SOD-123
J8: LOAD CELL; JST-PH-4
J9: FSR1; HDR-1X2
J10: FSR2; HDR-1X2
J11: FSR3; HDR-1X2
J12: FSR4; HDR-1X2
J13: STRETCH; HDR-1X2
J14: PIEZO; HDR-1X2
J15: HALL / LIMIT; HDR-1X3
R33, R34, R35, R36, R37, R42: 10k; R0805
R38: 10M; R0805
R39, R40: 1M; R0805
R41: 100k; R0805
TP12: HX_BASE; TESTPOINT-1.5
TP13: HX_XO; TESTPOINT-1.5
TP14: HX_DOUT; TESTPOINT-1.5
U8: HX711; SOP-16-N

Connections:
3V3: C26.1, C27.1, C28.1, D5.1 (C), J8.1, J9.1, J10.1, J11.1, J12.1, J13.1, J15.1, R39.1, R42.1, U8.1 (VSUP), U8.3 (AVDD), U8.16 (DVDD); also elsewhere on the board
FSR1_ADC: C29.1, J9.2, R33.1; also elsewhere on the board
FSR2_ADC: C30.1, J10.2, R34.1; also elsewhere on the board
FSR3_ADC: C31.1, J11.2, R35.1; also elsewhere on the board
FSR4_ADC: C32.1, J12.2, R36.1; also elsewhere on the board
GND: C25.2, C26.2, C27.2, C28.2, C29.2, C30.2, C31.2, C32.2, C33.2, C35.2, C36.2, D6.2 (A), J8.2, J14.2, J15.3, R33.2, R34.2, R35.2, R36.2, R37.2, R38.2, R40.2, U8.4 (VFB), U8.5 (AGND), U8.9 (INB-), U8.10 (INB+), U8.14 (XI), U8.15 (RATE); also elsewhere on the board
HALL_LIMIT: C36.1, J15.2, R42.2; also elsewhere on the board
HX_BASE: TP12.TP, U8.2 (BASE)
HX_DOUT: TP14.TP, U8.12 (DOUT); also elsewhere on the board
HX_SCK: U8.11 (PD_SCK); also elsewhere on the board
HX_VBG: C25.1, U8.6 (VBG)
HX_XO: TP13.TP, U8.13 (XO)
LC_A_N: J8.4, U8.7 (INA-)
LC_A_P: J8.3, U8.8 (INA+)
PIEZO_AC: C34.2, R39.2, R40.1, R41.1
PIEZO_ADC: C35.1, D5.2 (A), D6.1 (C), R41.2; also elsewhere on the board
PIEZO_IN: C34.1, J14.1, R38.1
STRETCH_ADC: C33.1, J13.2, R37.1; also elsewhere on the board

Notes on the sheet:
SIH26113 - MATERNITY ASSIST BELT - PROTOTYPE CARRIER BOARD
SHEET 5/7 - MECHANICAL SENSING (LOAD CELL, FSR, STRETCH, PIEZO, HALL)
NOT A MEDICAL DEVICE. Prototype for engineering evaluation only. Human-connected ECG is NOT isolated - see documentation/README.
4-layer FR-4 1.6 mm (L1 sig / L2 GND plane / L15 3V3 plane / L16 sig) | board 100 x 70 mm | lib SIH26113_Maternity_Assist_Belt.lbr | sheet 5 of 7
SHEET 5/7
LOAD CELL BRIDGE
HX711 24-BIT ADC
FSR DIVIDERS
PIEZO CONDITIONING
HALL / LIMIT

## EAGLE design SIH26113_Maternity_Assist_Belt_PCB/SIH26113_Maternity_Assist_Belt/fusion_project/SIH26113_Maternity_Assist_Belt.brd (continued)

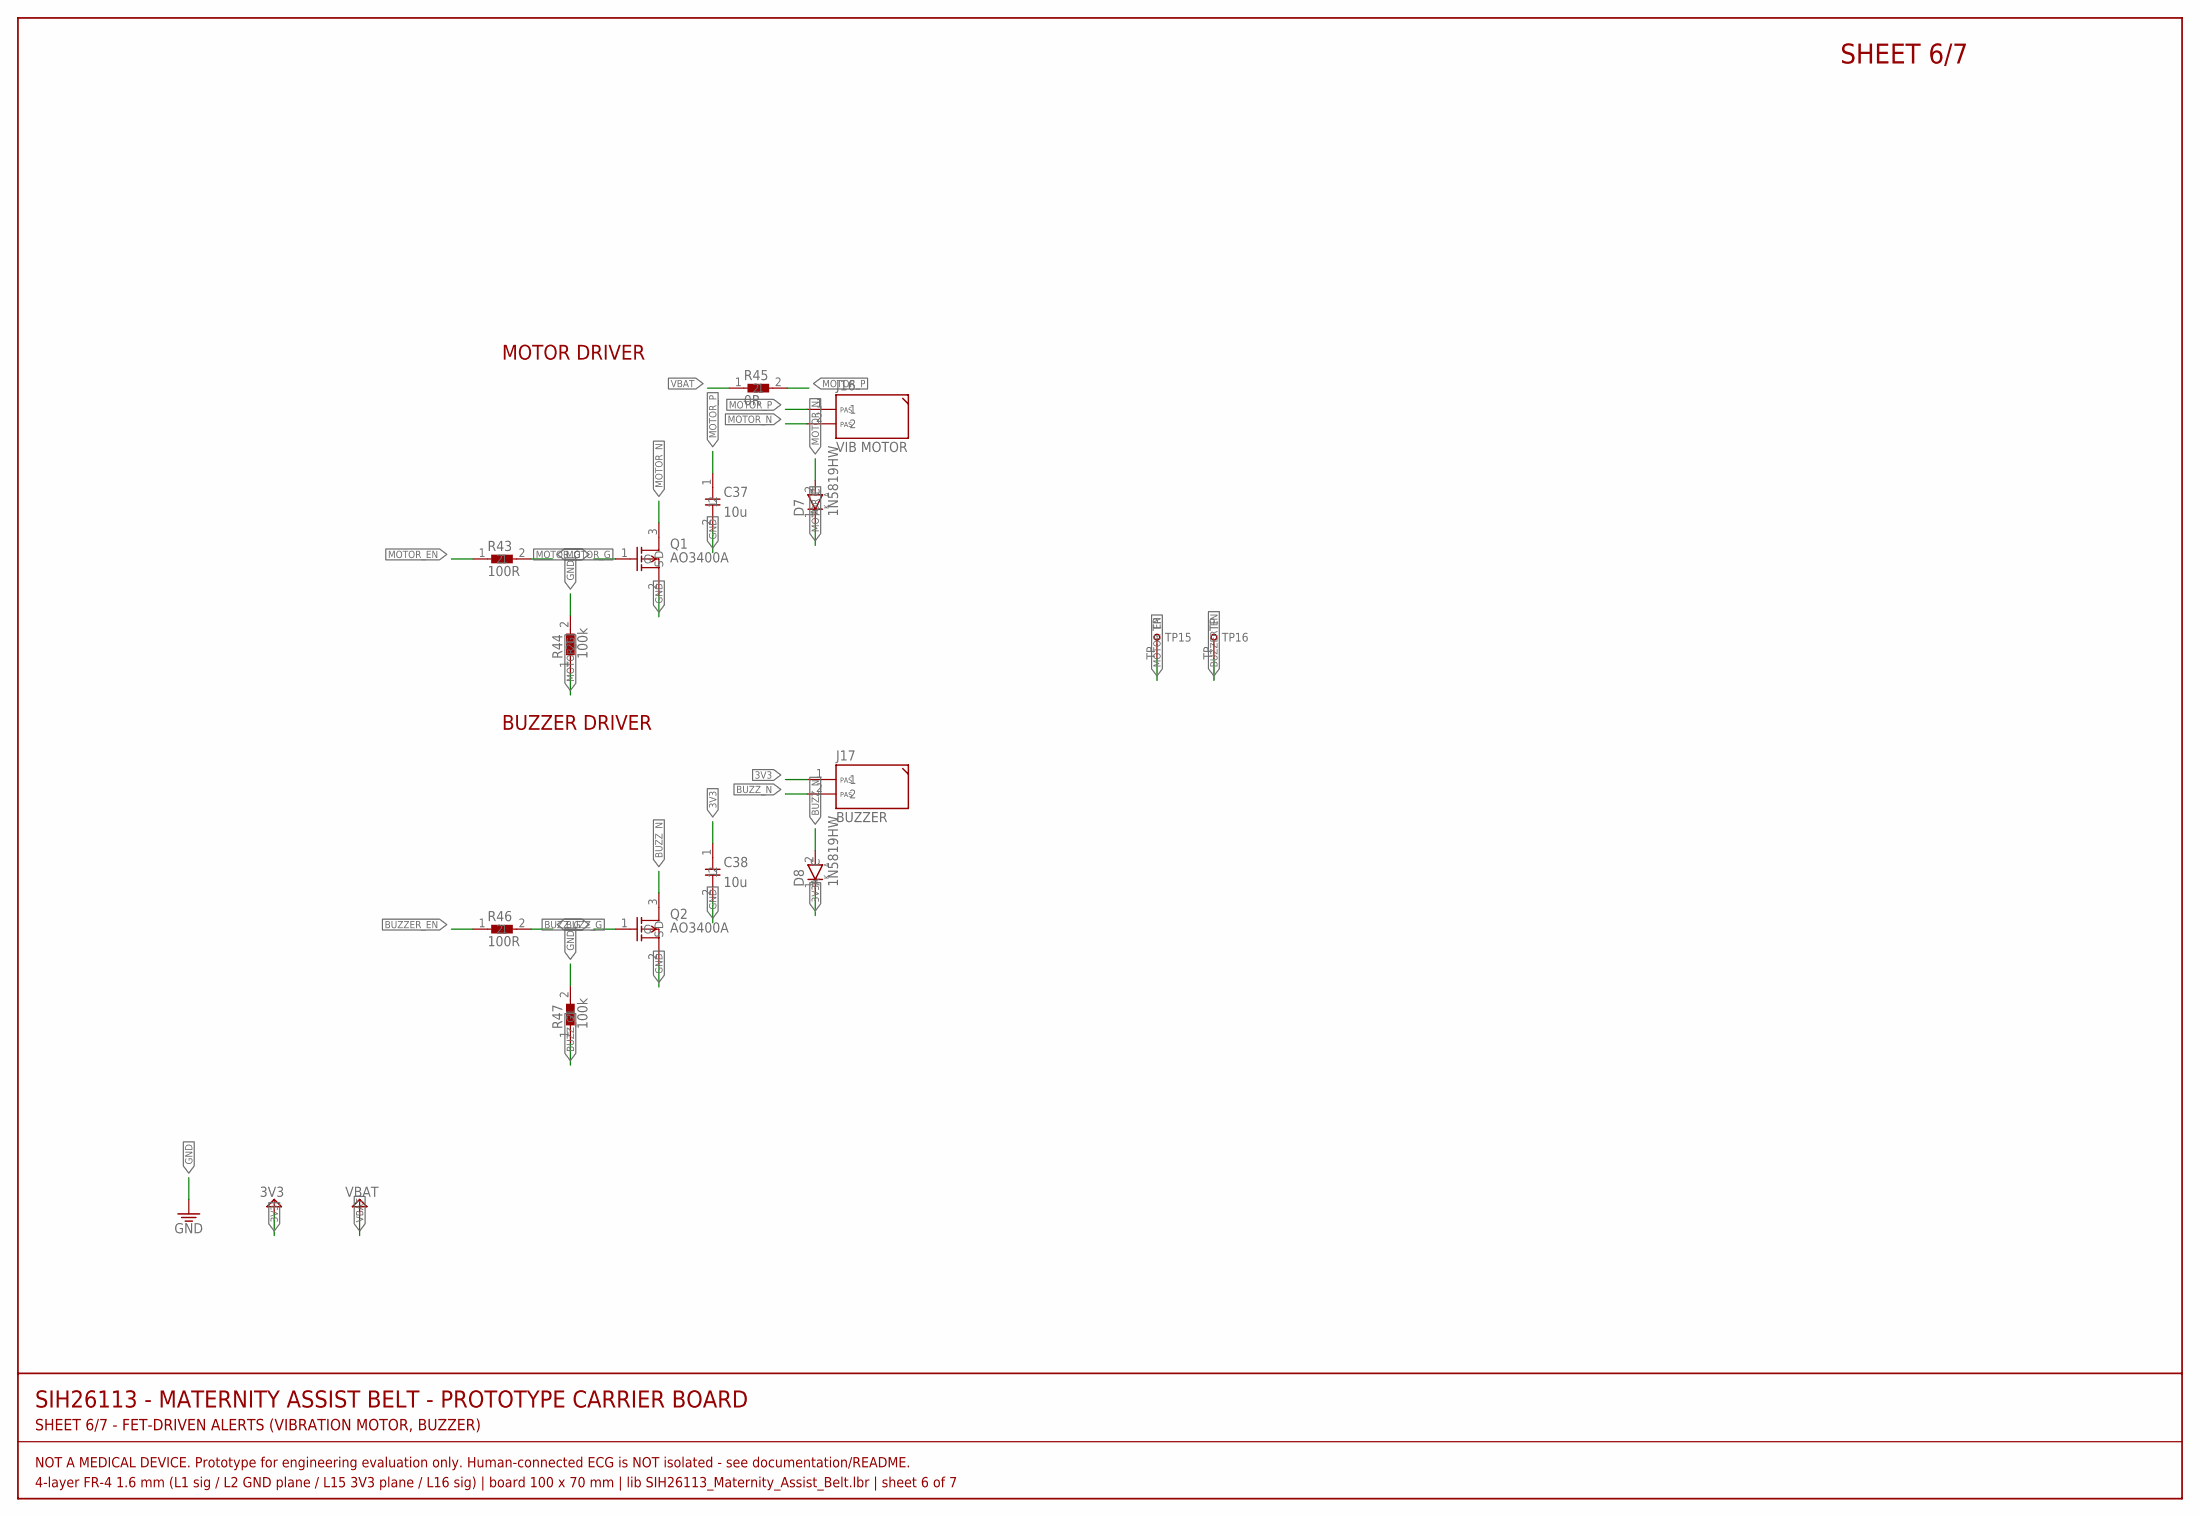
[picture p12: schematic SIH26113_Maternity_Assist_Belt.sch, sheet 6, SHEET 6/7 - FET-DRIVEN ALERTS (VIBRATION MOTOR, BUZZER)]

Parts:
C37, C38: 10u; C0805
D7, D8: 1N5819HW; SOD-123
J16: VIB MOTOR; HDR-1X2
J17: BUZZER; HDR-1X2
Q1, Q2: AO3400A; SOT-23-3
R43, R46: 100R; R0805
R44, R47: 100k; R0805
R45: 0R; R0805
TP15: MOTOR_EN; TESTPOINT-1.5
TP16: BUZZER_EN; TESTPOINT-1.5

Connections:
3V3: C38.1, D8.1 (C), J17.1; also elsewhere on the board
BUZZER_EN: R46.1, TP16.TP; also elsewhere on the board
BUZZ_G: Q2.1 (G), R46.2, R47.1
BUZZ_N: D8.2 (A), J17.2, Q2.3 (D)
GND: C37.2, C38.2, Q1.2 (S), Q2.2 (S), R44.2, R47.2; also elsewhere on the board
MOTOR_EN: R43.1, TP15.TP; also elsewhere on the board
MOTOR_G: Q1.1 (G), R43.2, R44.1
MOTOR_N: D7.2 (A), J16.2, Q1.3 (D)
MOTOR_P: C37.1, D7.1 (C), J16.1, R45.2
VBAT: R45.1; also elsewhere on the board

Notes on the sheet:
SIH26113 - MATERNITY ASSIST BELT - PROTOTYPE CARRIER BOARD
SHEET 6/7 - FET-DRIVEN ALERTS (VIBRATION MOTOR, BUZZER)
NOT A MEDICAL DEVICE. Prototype for engineering evaluation only. Human-connected ECG is NOT isolated - see documentation/README.
4-layer FR-4 1.6 mm (L1 sig / L2 GND plane / L15 3V3 plane / L16 sig) | board 100 x 70 mm | lib SIH26113_Maternity_Assist_Belt.lbr | sheet 6 of 7
SHEET 6/7
MOTOR DRIVER
BUZZER DRIVER

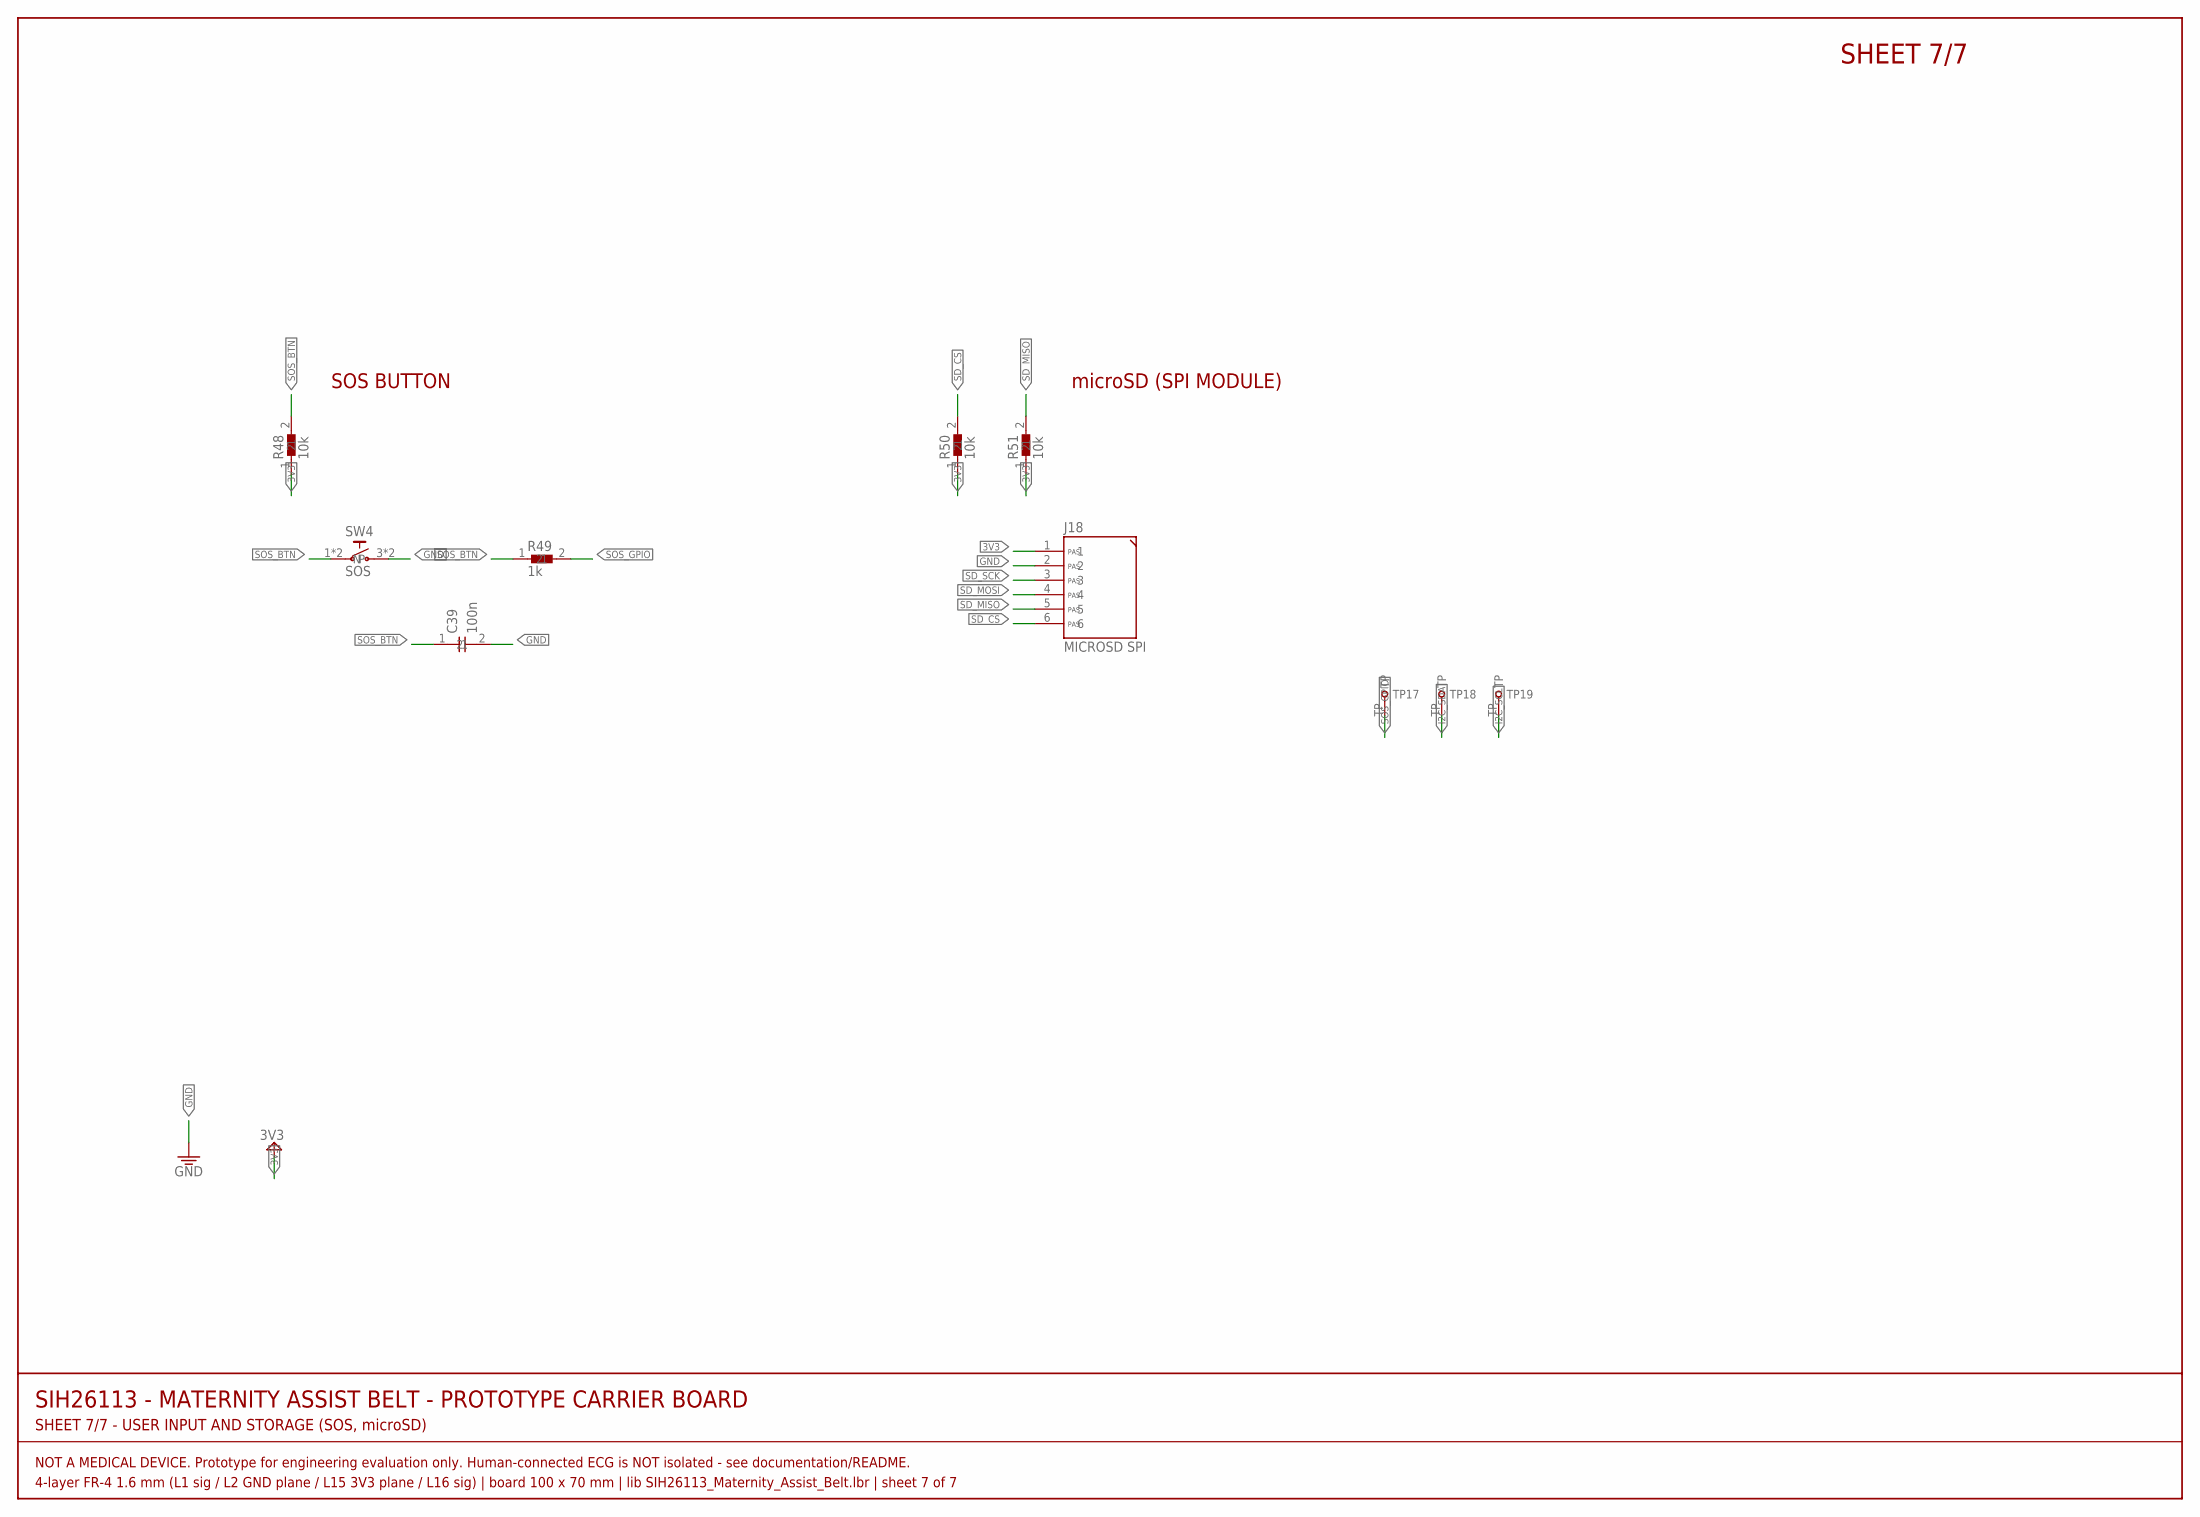
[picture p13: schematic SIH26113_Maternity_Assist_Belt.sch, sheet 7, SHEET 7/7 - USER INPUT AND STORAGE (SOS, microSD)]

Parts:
C39: 100n; C0805
J18: MICROSD SPI; HDR-1X6
R48, R50, R51: 10k; R0805
R49: 1k; R0805
SW4: SOS; TACT-6X6-THT
TP17: SOS_GPIO; TESTPOINT-1.5
TP18: I2C_SDA; TESTPOINT-1.5
TP19: I2C_SCL; TESTPOINT-1.5

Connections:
3V3: J18.1, R48.1, R50.1, R51.1; also elsewhere on the board
GND: C39.2, J18.2, SW4.3 (N), SW4.4 (N); also elsewhere on the board
I2C_SCL: TP19.TP; also elsewhere on the board
I2C_SDA: TP18.TP; also elsewhere on the board
SD_CS: J18.6, R50.2; also elsewhere on the board
SD_MISO: J18.5, R51.2; also elsewhere on the board
SD_MOSI: J18.4; also elsewhere on the board
SD_SCK: J18.3; also elsewhere on the board
SOS_BTN: C39.1, R48.2, R49.1, SW4.1, SW4.2
SOS_GPIO: R49.2, TP17.TP; also elsewhere on the board

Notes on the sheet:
SIH26113 - MATERNITY ASSIST BELT - PROTOTYPE CARRIER BOARD
SHEET 7/7 - USER INPUT AND STORAGE (SOS, microSD)
NOT A MEDICAL DEVICE. Prototype for engineering evaluation only. Human-connected ECG is NOT isolated - see documentation/README.
4-layer FR-4 1.6 mm (L1 sig / L2 GND plane / L15 3V3 plane / L16 sig) | board 100 x 70 mm | lib SIH26113_Maternity_Assist_Belt.lbr | sheet 7 of 7
SHEET 7/7
SOS BUTTON
microSD (SPI MODULE)

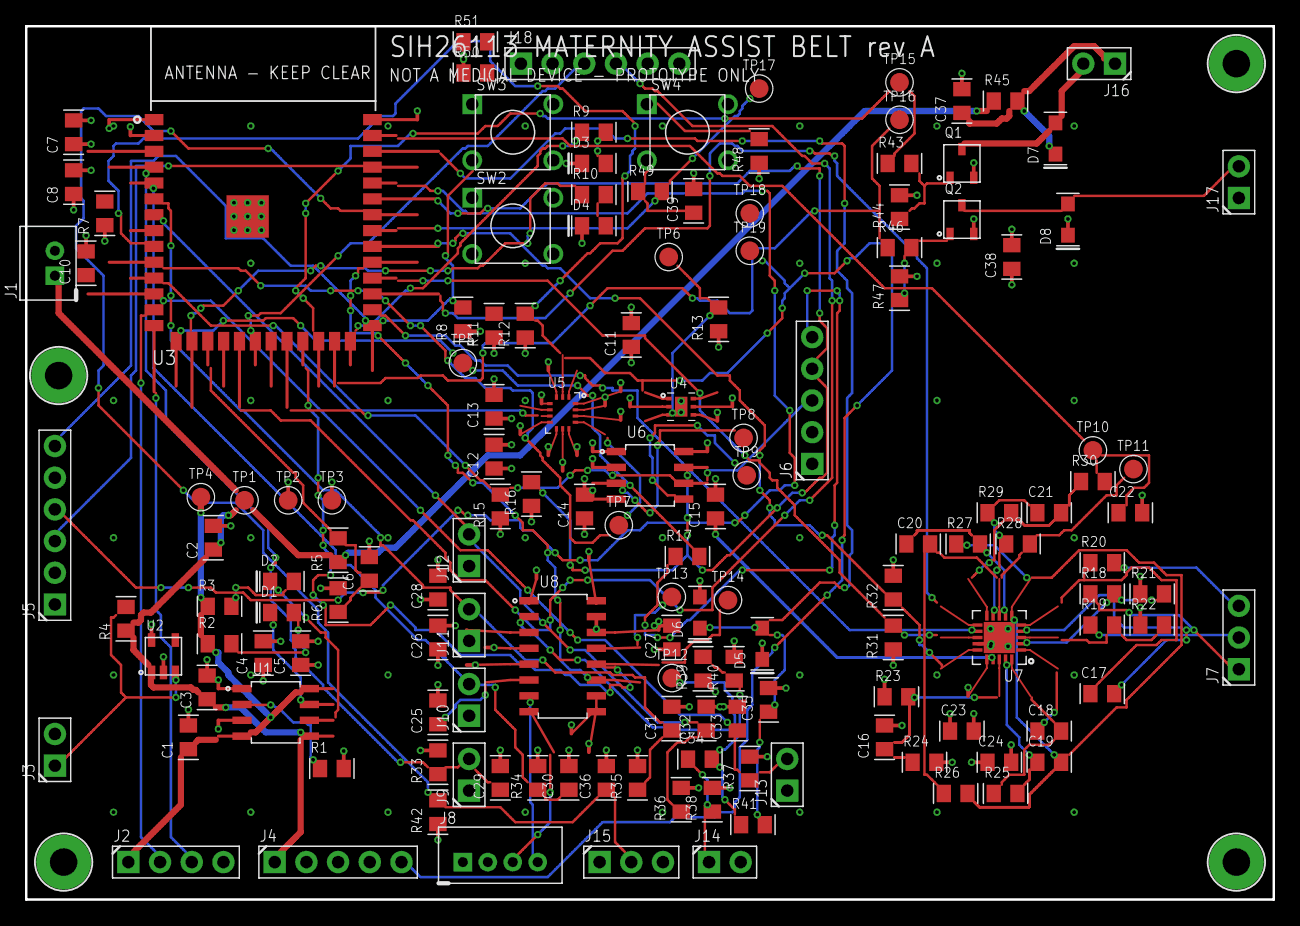
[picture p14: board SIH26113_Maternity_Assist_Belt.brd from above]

Board: 4 copper layers, 100.0 x 70.0 mm, 150 parts (0 on the bottom side), 82 nets.

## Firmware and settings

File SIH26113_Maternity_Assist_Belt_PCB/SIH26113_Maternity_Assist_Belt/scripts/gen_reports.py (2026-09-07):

"""
gen_reports.py - Emit MANUFACTURING_CHECK.md and FINAL_REPORT.md.

Both are generated from the design model plus the router/DRC output, so the
numbers in them are the numbers the files actually contain.

Run:  python scripts/gen_reports.py
"""

from __future__ import annotations

import json
import pathlib
import re
import sys
import xml.etree.ElementTree as ET
from collections import Counter

sys.path.insert(0, str(pathlib.Path(__file__).parent))

import design as D                                          # noqa: E402
import geom                                                 # noqa: E402
from lib_defs import (                                      # noqa: E402
    DEVICESETS,
    LIBRARY_NAME,
    PACKAGE_HEIGHT,
    PACKAGES,
    SYMBOLS,
)

ROOT = pathlib.Path(__file__).resolve().parent.parent
DOCS = ROOT / "documentation"
BRD = ROOT / "pcb" / f"{LIBRARY_NAME}.brd"

HEADER = ("<!-- GENERATED by scripts/gen_reports.py from scripts/design.py "
          "plus the router and DRC output. Do not edit by hand: re-run the "
          "script. -->\n")


def _json(name: str) -> dict:
    f = ROOT / "pcb" / name
    return json.loads(f.read_text(encoding="utf-8")) if f.exists() else {}


def _board():
    txt = BRD.read_text(encoding="utf-8")
    return ET.fromstring(txt.split("\n", 2)[2]).find("./drawing/board")


def _drc_min_clearance(drc: dict) -> str:
    for n in drc.get("notes", []):
        m = re.search(r"MINIMUM COPPER CLEARANCE ANYWHERE ON THE BOARD: "
                      r"([\d.]+) mm", n)
        if m:
            return m.group(1)
    return "see DRC_REPORT.md"


# ===========================================================================
def gen_manufacturing_check() -> str:
    rep, drc = _json("route_report.json"), _json("drc_result.json")
    brd = _board()
    minclear = _drc_min_clearance(drc)

    drills = sorted({float(v.get("drill"))
                     for v in brd.findall("./signals/signal/via")})
    pad_drills = sorted({float(pd.get("drill"))
                         for lib in brd.findall("./libraries/library")
                         for pd in lib.findall(".//package/pad")})
    widths = sorted({float(w.get("width"))
                     for w in brd.findall("./signals/signal/wire")})

    tall = sorted(
        ((PACKAGE_HEIGHT[geom.DS[p.deviceset].package][0],
          PACKAGE_HEIGHT[geom.DS[p.deviceset].package][1], p.ref,
          geom.DS[p.deviceset].package)
         for p in D.PARTS if geom.DS[p.deviceset].package in PACKAGE_HEIGHT),
        reverse=True)

    edges = {"bottom (y < 6 mm)": [], "left (x < 6 mm)": [],
             "right (x > 94 mm)": [], "top (y > 64 mm)": [],
             "interior": []}
    for p in D.PARTS:
        if not p.ref.startswith("J"):
            continue
        if p.by < 6:
            edges["bottom (y < 6 mm)"].append(p.ref)
        elif p.bx < 6:
            edges["left (x < 6 mm)"].append(p.ref)
        elif p.bx > 94:
            edges["right (x > 94 mm)"].append(p.ref)
        elif p.by > 64:
            edges["top (y > 64 mm)"].append(p.ref)
        else:
            edges["interior"].append(p.ref)

    assy = Counter()
    HARD = {"LFCSP-20-4X4-P050", "WSON-6-DRV0006B", "LGA-14L-2.5X3.0"}
    for p in D.PARTS:
        pkg = geom.DS[p.deviceset].package
        if pkg is None:
            continue
        assy["reflow / hot air only" if pkg in HARD
             else ("reflow or hot air (castellated)"
                   if pkg == "ESP32-S3-WROOM-1" else "hand-solderable")] += 1

    L = [HEADER, "# MANUFACTURING CHECK - SIH26113 Maternity Assist Belt\n",
         "Every item the brief asks to check before declaring the design "
         "complete, with the value the files actually contain. Measured "
         "figures come from `validate_drc.py` re-reading the emitted `.brd`; "
         "assumptions are labelled as such.\n",
         "> **No fabricator capability is assumed as verified.** The numbers "
         "below are what the board *requires*. Item 7 is the one that has to "
         "be checked against a specific fab's quoted capability before "
         "ordering - see `REQUIRES_CONFIRMATION.md` H6.\n",
         "| # | Item | Value | Status |", "|---|---|---|---|",
         f"| 1 | PCB dimensions | **{D.BOARD_W:.0f} x {D.BOARD_H:.0f} mm** "
         f"({D.BOARD_W * D.BOARD_H / 100:.0f} cm2) | set in `design.py`, "
         f"outline on layer 20 |",
         f"| 2 | Board thickness | **{D.BOARD_THICKNESS} mm** FR-4 | "
         f"**assumption** - standard; dielectric split "
         f"0.36 / 0.71 / 0.36 mm declared in the rule set |",
         f"| 3 | Layer count | **{D.BOARD_LAYERS}** - "
         f"`(1*2*15*16)`; L2 = GND plane, L15 = 3V3 plane | verified in the "
         f"`.brd` design rules |",
         f"| 4 | Copper thickness | **{D.COPPER_OZ} oz (35 um)** outer and "
         f"inner | **assumption** - drives the trace-width calculation in "
         f"`POWER_BUDGET.md` |",
         f"| 5 | Via sizes | drill **{', '.join(f'{d:g}' for d in drills)} "
         f"mm**, pad 0.55-0.60 mm | {len(brd.findall('./signals/signal/via'))}"
         f" vias, all through (`extent 1-16`) |",
         f"| 6 | Minimum trace width | **{min(widths):g} mm** "
         f"(fine-pitch escapes); {', '.join(f'{w:g}' for w in widths)} mm in "
         f"use | measured from the emitted tracks |",
         f"| 7 | Minimum clearance | **{minclear} mm measured anywhere on the "
         f"board** | 0.15 mm general rule; {D.FINE_PITCH_CLEARANCE} mm inside "
         f"the 4 declared fine-pitch fan-outs. **Needs a fab quoting 5 mil / "
         f"0.127 mm** |",
         f"| 8 | Drill sizes | vias "
         f"{', '.join(f'{d:g}' for d in drills)} mm; plated pads "
         f"{', '.join(f'{d:g}' for d in pad_drills)} mm | JST PH 0.8 mm is "
         f"within JST's ø0.7 +0.1 spec; M2 holes 2.2 mm |",
         f"| 9 | Component courtyard | **no overlaps**, "
         f"{D.COURTYARD_GAP} mm minimum gap between courtyards | DRC rule D2, "
         f"enforced by the placement pass |",
         f"| 10 | Connector accessibility | "
         f"{sum(len(v) for k, v in edges.items() if k != 'interior')} of "
         f"{sum(len(v) for v in edges.values())} connectors are on a board "
         f"edge; see the table below | the "
         f"{len(edges['interior'])} interior ones all take a flying lead from "
         f"an off-board transducer |",
         f"| 11 | Antenna keep-out | **{D.ANTENNA_KEEPOUT[2] - D.ANTENNA_KEEPOUT[0]:.0f}"
         f" x {D.ANTENNA_KEEPOUT[3] - D.ANTENNA_KEEPOUT[1]:.1f} mm** at the "
         f"top edge, flush | no pad, via or track inside it (DRC rule D3); "
         f"both plane polygons are drawn as an L that omits it |",
         f"| 12 | Mounting holes | **{len(D.MOUNT_HOLES)} x M2**, 2.2 mm "
         f"drill, 4.4 mm plated annulus on GND | `H3` is at (2.6, 42) not the "
         f"top-left corner, because that corner is inside the antenna "
         f"keep-out |",
         "| 13 | Assembly feasibility | see the assembly table below | "
         "**3 parts need a stencil and reflow / hot air**; everything else is "
         "hand-solderable |",
         "| 14 | Component availability | **NOT VERIFIED** | distributor stock "
         "could not be checked from this environment. `BOM.csv` carries empty "
         "Supplier / Supplier PN / Lifecycle columns rather than invented "
         "ones |",
         "| 15 | Polarity markings | diodes and LEDs carry a silkscreen "
         "cathode bar; pad 1 = cathode on every 2-pin polarised footprint | "
         "in the library |",
         "| 16 | Pin 1 markings | silkscreen dot or chamfer on every "
         "multi-pin part; **pad 1 is square** on every through-hole connector "
         "| in the library |",
         f"| 17 | Silkscreen readability | reference designators at "
         f"0.8-1.1 mm vector text | **assumption** - most fabs hold 0.8 mm "
         f"with a 0.15 mm stroke; confirm, see `REQUIRES_CONFIRMATION.md` "
         f"L3 |",
         "| 18 | Solder-paste / stencil | **required** | order the stencil "
         "with the boards - see item 13 |",
         "| 19 | Manufacturing outputs | **NOT GENERATED** | Gerbers and "
         "drill files need Fusion's CAM processor; build guide step 19 |",
         "\n## Connector accessibility (item 10)\n",
         "| Edge | Connectors |", "|---|---|"]
    for k, v in edges.items():
        if v:
            L.append(f"| {k} | {', '.join(sorted(v))} |")
    L += ["\nThe interior connectors are the four FSR headers (`J9`-`J12`), "
          "the stretch-sensor header (`J13`) and the optional second AS5600 "
          "(`J6`). All six take a flying lead from a transducer mounted on "
          "the belt, so none of them needs a board edge - and putting the FSR "
          "headers in a vertical row inboard, rather than a long horizontal "
          "row along the edge, was deliberate: a row of through-hole pads "
          "across the board is a wall through both signal layers. See "
          "`DESIGN_ASSUMPTIONS.md` 14.\n",
          "## Assembly feasibility (item 13)\n",
          "| Method | Placements |", "|---|---|"]
    for k, v in sorted(assy.items(), key=lambda kv: -kv[1]):
        L.append(f"| {k} | {v} |")
    L += ["\nThe three parts that cannot be soldered with an iron are the "
          "**AD8232** (0.5 mm-pitch QFN with a 2.50 mm exposed pad), the "
          "**LSM6DSOX** (0.5 mm LGA) and the **TMP117** (0.65 mm WSON with a "
          "thermal pad).\n",
          "## Mechanical envelope\n",
          "No STEP geometry is attached to these footprints, so there is no "
          "solid model and **no 3D interference check has been done**. What "
          "exists instead is a height table (`PACKAGE_HEIGHT` in "
          "`lib_defs.py`) and an isometric extrusion of it in "
          "`renders/pcb_3d.png` - enough to size an enclosure and spot a "
          "connector that will foul a lid, not enough to certify clearance.\n",
          "| Height | Ref | Package | Height source |", "|---|---|---|---|"]
    seen_pkg = set()
    for h, src, ref, pkg in tall:
        if h <= 0 or pkg in seen_pkg:
            continue
        seen_pkg.add(pkg)
        L.append(f"| **{h:.2f} mm** | {ref} | `{pkg}` | {src} |")
    L += [f"\nTallest part: **{tall[0][2]} at {tall[0][0]:.1f} mm** above the "
          f"board, so the minimum internal enclosure height is about "
          f"{D.BOARD_THICKNESS + tall[0][0] + 1.5:.1f} mm including the "
          f"substrate and a little clearance.\n",
          "**Keep the battery and any metal at least 10 mm from the antenna "
          "region** (top edge, x 9-29 mm). A Li-Po pack laid against it will "
          "cost most of the radio range.\n"]
    return "\n".join(L) + "\n"


# ===========================================================================
def gen_final_report() -> str:
    rep, drc = _json("route_report.json"), _json("drc_result.json")
    brd = _board()
    minclear = _drc_min_clearance(drc)
    d6 = [e for e in drc.get("errors", []) if e.startswith("[D6]")]
    other = [e for e in drc.get("errors", []) if not e.startswith("[D6]")]
    conceded = rep.get("conceded_for_clearance", [])
    placed = [p for p in D.PARTS if geom.DS[p.deviceset].package is not None]

    ics = [p for p in D.PARTS if p.ref.startswith("U")]

    L = [HEADER, "# FINAL REPORT - SIH26113 Maternity Assist Belt\n",
         "> **NOT A MEDICAL DEVICE.** Prototype for engineering evaluation. "
         "The ECG channel is not isolated and the board carries no battery "
         "protection circuit. Read `REQUIRES_CONFIRMATION.md` items B1 and B2 "
         "before applying power.\n",
         "## 1. What was created\n",
         "A complete Autodesk EAGLE 9 / Fusion Electronics project for the "
         "SIH26113 Maternity Assist Belt carrier board: a component library "
         "with every pinout verified against the manufacturer's datasheet, a "
         # Counted, not asserted: hard-coded counts in prose have
         # drifted twice in this project already.
         f"seven-sheet schematic, a placed and routed four-layer board, "
         f"{len(list((ROOT / 'renders').glob('*.png')))} "
         f"renders drawn from those files, and "
         f"{len(list((ROOT / 'documentation').glob('*')))} documents.\n",
         "Everything is generated from one source model "
         "(`scripts/design.py`), so the library, schematic, board, netlist, "
         "GPIO table, BOM and reports cannot disagree with each other. The "
         "generators verify themselves: `generate_schematic.py` re-parses its "
         "own output and asserts the netlist matches the model exactly, and "
         "`generate_board.py` does the same for elements and signals.\n",
         "## 2. Exact files generated\n",
         "| Path | What it is |", "|---|---|",
         f"| [`libraries/{LIBRARY_NAME}.lbr`](../libraries/{LIBRARY_NAME}.lbr)"
         f" | EAGLE 9 library: {len(PACKAGES)} footprints, {len(SYMBOLS)} "
         f"symbols, {len(DEVICESETS)} devices |",
         f"| [`schematic/{LIBRARY_NAME}.sch`](../schematic/{LIBRARY_NAME}.sch)"
         f" | 7 sheets, {len(D.PARTS)} parts, {len(D.NETS)} nets |",
         f"| [`pcb/{LIBRARY_NAME}.brd`](../pcb/{LIBRARY_NAME}.brd) | "
         f"4-layer board, {D.BOARD_W:.0f} x {D.BOARD_H:.0f} mm |",
         "| [`pcb/route_report.json`](../pcb/route_report.json) | the "
         "router's own output, machine-readable |",
         "| [`pcb/drc_result.json`](../pcb/drc_result.json) | DRC findings, "
         "machine-readable |"]

    for nm, desc in [
        ("COMPONENT_VERIFICATION.md", "every pinout and footprint with its source"),
        ("DESIGN_ASSUMPTIONS.md", "every decision, and the 7 architecture changes"),
        ("ECG_FRONTEND_DESIGN.md", "the AD8232 circuit, with the arithmetic"),
        ("GROUNDING_NOTES.md", "why one ground plane and not a split"),
        ("POWER_BUDGET.md", "itemised current budget and dropout analysis"),
        ("GPIO_ASSIGNMENT.md", "all 41 module pins [generated]"),
        ("NETLIST.md", "every net, source, load and routing state [generated]"),
        ("BOM.md", "bill of materials [generated]"),
        ("BOM.csv", "bill of materials, machine-readable [generated]"),
        ("ERC_REPORT.md", "rules, result and declared exceptions [generated]"),
        ("DRC_REPORT.md", "rules, result, clearance and airwires [generated]"),
        ("MANUFACTURING_CHECK.md", "the 19-point pre-fabrication check [generated]"),
        ("PROJECT_STATISTICS.md", "counts and metrics [generated]"),
        ("FINAL_REVIEW.md", "27-point independent design review"),
        ("PCB_BUILD_GUIDE.md", "20 steps, Fusion to fabrication"),
        ("REQUIRES_CONFIRMATION.md", "open items, worst first"),
        ("FINAL_REPORT.md", "this document [generated]"),
    ]:
        L.append(f"| [`documentation/{nm}`](./{nm}) | {desc} |")
    for nm, desc in [
        ("schematic_p1.png", "sheet 1 - power entry, charging, 3V3"),
        ("schematic_p2.png", "sheet 2 - ESP32-S3 core"),
        ("schematic_p3.png", "sheet 3 - I2C sensors"),
        ("schematic_p4.png", "sheet 4 - ECG analog front end"),
        ("schematic_p5.png", "sheet 5 - mechanical sensing"),
        ("schematic_p6.png", "sheet 6 - FET-driven alerts"),
        ("schematic_p7.png", "sheet 7 - user input and storage"),
        ("pcb_top.png", "layer 1 copper, pads, silkscreen"),
        ("pcb_bottom.png", "layer 16 copper, mirrored"),
        ("pcb_layers.png", "all four copper layers overlaid"),
        ("pcb_assembly.png", "placement, designators and zones"),
        ("pcb_3d.png", "isometric mechanical envelope"),
    ]:
        L.append(f"| [`renders/{nm}`](../renders/{nm}) | {desc} |")
    L.append("| [`scripts/`](../scripts/) | the 13 generators, routers and "
             "validators that produce all of the above |")

    # ---- 3 / 4. components and variants ---------------------------------
    L += ["\n## 3 & 4. Exact components and variants used\n",
          "Every pinout below was read from the manufacturer's datasheet; the "
          "citation for each is in "
          "[`COMPONENT_VERIFICATION.md`](./COMPONENT_VERIFICATION.md).\n",
          "| Ref | Exact part | Manufacturer | Package | Why this variant |",
          "|---|---|---|---|---|"]
    WHY = {
        "U1": "SOP-8 is hand-solderable and the datasheet gives R_PROG "
              "directly; charge set to 500 mA, not 1 A, because this "
              "footprint has no thermal land",
        "U2": "600 mA guaranteed minimum against a 510 mA worst case, and an "
              "LDO rather than a switcher because the ECG front end is 20 mm "
              "away",
        "U3": "**-N8R2 is mandatory** - octal-PSRAM variants reserve "
              "IO35/36/37, which this design uses",
        "U4": "WSON (DRV) is the only variant in production; TI publish its "
              "land pattern",
        "U5": "LGA-14, I2C mode 1, address 0x6A (SA0 to GND)",
        "U6": "SOIC-8 - by far the easiest fine-position sensor to assemble; "
              "address 0x36 is fixed, which forced the second I2C bus",
        "U7": "**supply 2.0-3.5 V only**, so it is on 3V3 and never on VBAT",
        "U8": "SOP-16, ratiometric to AVDD so sharing the 3V3 rail costs "
              "nothing; RATE grounded for 10 Hz",
    }
    for p in sorted(ics, key=lambda q: int(q.ref[1:])):
        L.append(f"| `{p.ref}` | **{p.mpn or p.value}** | "
                 f"{p.manufacturer or '-'} | "
                 f"`{geom.DS[p.deviceset].package}` | "
                 f"{WHY.get(p.ref, p.desc)} |")
    L += ["| `Q1`, `Q2` | AO3400A (or pin-compatible logic-level N-FET) | "
          "Alpha & Omega | `SOT-23-3` | V_GS(th) low enough for 3.3 V drive |",
          "| `D5`-`D8` | 1N5819HW | generic | `SOD-123` | 40 V / 1 A Schottky "
          "for flyback and piezo clamping |",
          "| `J1`, `J8` | S2B-PH-K-S / S4B-PH-K-S | JST | `JST-PH-2/4` | "
          "PCB hole ø0.7 +0.1 mm read from JST's own board-layout figure |",
          "\nFull line-item list with quantities: "
          "[`BOM.md`](./BOM.md) / [`BOM.csv`](./BOM.csv).\n"]

    # ---- 5. unresolved --------------------------------------------------
    L += ["## 5. Unresolved components\n",
          "| Item | State | Where it is recorded |", "|---|---|---|",
          "| **MAX17048 fuel gauge** | **not placed.** Datasheet unreachable "
          "from this environment, so neither pinout nor land pattern could be "
          "verified. Replaced by header `J4` for a breakout, plus a "
          "470k/470k VBAT divider on `IO9` that works either way | "
          "`REQUIRES_CONFIRMATION.md` H1 |",
          "| **Li-Po protection (DW01A + FS8205A)** | **not placed.** Pinouts "
          "unverifiable; a protected cell/pack is required at `J1` instead | "
          "H1 / **B1 (BLOCKING)** |",
          "| **Stretch sensor** | not selected. `R37` = 10 k is an explicit "
          "**placeholder** - the correct value is the geometric mean of the "
          "chosen sensor's resistance band | H2 |",
          "| **Load cell** | not selected. Bridge resistance and mV/V "
          "sensitivity unknown | H3 |",
          "| **Vibration motor** | not selected. Voltage rating decides "
          "whether `R45` stays at 0 R | **B3 (BLOCKING)** |",
          "| **Buzzer** | active-magnetic assumed; passive piezo works on the "
          "same circuit with PWM | M3 |",
          "| **Piezo film, FSRs, electrodes, hall switch** | not selected; "
          "FSR dividers sized for an FSR402-class part | M4 / "
          "`DESIGN_ASSUMPTIONS.md` 7.1 |",
          "| **Tactile switches** | standard 6.5 x 4.5 mm grid assumed; "
          "confirm the vendor part | H4 |",
          ""]
    L += _sections_6_to_15(rep, drc, brd, minclear, d6, other, conceded,
                           placed)
    return "\n".join(L) + "\n"
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

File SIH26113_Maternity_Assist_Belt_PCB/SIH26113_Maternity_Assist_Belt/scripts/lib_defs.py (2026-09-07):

"""
lib_defs.py - Single source of truth for the SIH26113 Maternity Assist Belt
EAGLE / Fusion Electronics library.

Every footprint dimension below is either
  (V) taken from the manufacturer's own package-outline / recommended
      land-pattern drawing (source cited inline), or
  (I) computed from IPC-7351B Nominal (Level B) density for a generic
      package family, or
  (S) a de-facto standard geometry (2.54 mm headers, M2 mounting hole).

Nothing here is estimated from a picture of a block diagram.

See ../documentation/COMPONENT_VERIFICATION.md for the full audit trail.
"""

from __future__ import annotations

from eagle_common import (
    Circle,
    DeviceSet,
    Hole,
    Package,
    Pad,
    Pin,
    Rect,
    Smd,
    Symbol,
    Text,
    Wire,
    box_symbol,
    chip_package,
    gullwing_package,
    header_package,
    sot23_package,
)

# EAGLE pin body lengths, in mm, keyed by the length attribute.
PIN_LEN = {"point": 0.0, "short": 2.54, "middle": 5.08, "long": 7.62}

# Short human-readable annotation for each EAGLE electrical direction.  These
# are drawn on layer 97 (Info) inside the symbol so the printed schematic
# states the pin type explicitly, as well as carrying it in the ERC model.
DIR_LABEL = {
    "in": "IN",
    "out": "OUT",
    "io": "I/O",
    "oc": "OC",
    "pwr": "PWR",
    "pas": "PAS",
    "hiz": "HIZ",
    "nc": "NC",
    "sup": "SUP",
}


# ---------------------------------------------------------------------------
# Symbol pin placement helpers
# ---------------------------------------------------------------------------
def _pin(side: str, name: str, hw: float, hh: float, offset: float,
         direction: str, length: str = "middle") -> tuple[Pin, Text]:
    """Create a pin on `side` of a box plus its type annotation text."""
    L = PIN_LEN[length]
    if side == "L":
        p = Pin(name, -hw - L, offset, length=length, direction=direction, rot="R0")
        t = Text(-hw + 0.7, offset - 0.55, 0.9, 97, DIR_LABEL[direction])
    elif side == "R":
        p = Pin(name, hw + L, offset, length=length, direction=direction, rot="R180")
        t = Text(hw - 0.7, offset - 0.55, 0.9, 97, DIR_LABEL[direction],
                 align="bottom-right")
    elif side == "T":
        p = Pin(name, offset, hh + L, length=length, direction=direction, rot="R270")
        t = Text(offset + 0.6, hh - 0.7, 0.9, 97, DIR_LABEL[direction],
                 rot="R90", align="bottom-right")
    elif side == "B":
        p = Pin(name, offset, -hh - L, length=length, direction=direction, rot="R90")
        t = Text(offset - 0.6, -hh + 0.7, 0.9, 97, DIR_LABEL[direction], rot="R90")
    else:
        raise ValueError(side)
    return p, t


def make_ic_symbol(name: str, description: str, width: float,
                   left: list[tuple[str, str]], right: list[tuple[str, str]],
                   *, pitch: float = 2.54, top_pad: float = 2.54,
                   extra: list | None = None) -> Symbol:
    """Build a rectangular IC symbol from ordered (pin_name, direction) lists."""
    rows = max(len(left), len(right))
    height = (rows - 1) * pitch + 2 * top_pad
    hw, hh = width / 2.0, height / 2.0
    y0 = (rows - 1) * pitch / 2.0
    pins: list = []
    labels: list = []
    for i, (pn, d) in enumerate(left):
        p, t = _pin("L", pn, hw, hh, y0 - i * pitch, d)
        pins.append(p)
        labels.append(t)
    for i, (pn, d) in enumerate(right):
        p, t = _pin("R", pn, hw, hh, y0 - i * pitch, d)
        pins.append(p)
        labels.append(t)
    if extra:
        labels.extend(extra)
    return box_symbol(name, description, pins, width=width, height=height,
                      labels=labels)


# ===========================================================================
# PACKAGES
# ===========================================================================
PACKAGES: list[Package] = []
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

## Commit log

2026-09-07 Document PCB architecture in prompt
2026-09-07 Add PCB architecture image
2026-09-07 Add maternity assist belt project artifacts
    [BOM.csv, SIH26113_Maternity_Assist_Belt.brd, SIH26113_Maternity_Assist_Belt.sch]
